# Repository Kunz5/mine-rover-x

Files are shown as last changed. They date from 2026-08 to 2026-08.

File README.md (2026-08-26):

# MineRoverX

**A four-wheeled ground robot that sweeps for buried metal, stops when it finds
something, and drops a marker where it stopped.**

Custom-designed chassis, 3D-printed rack-and-pinion sweep mechanism, ESP32
firmware, and a metal detector that had to be physically modified before it
could talk to a microcontroller at all.






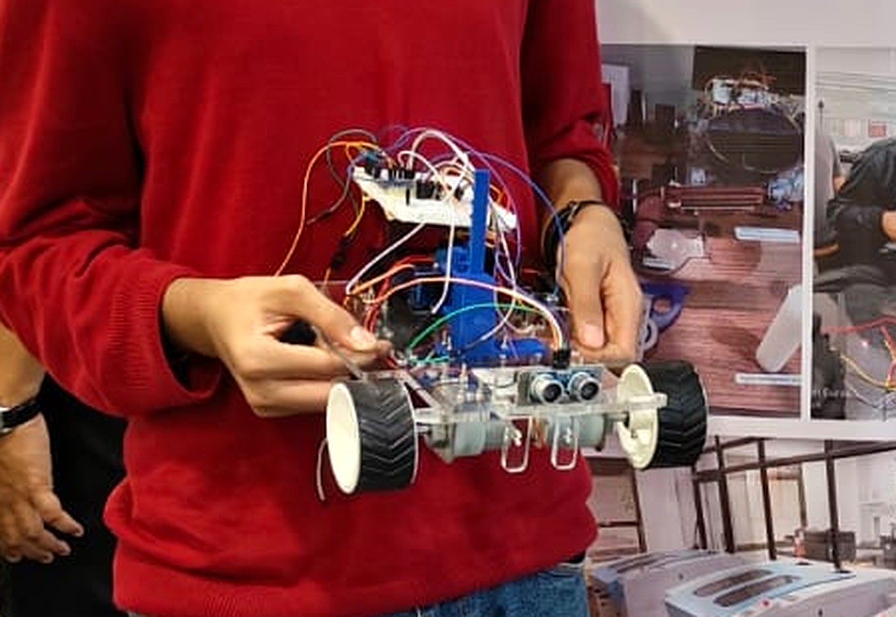
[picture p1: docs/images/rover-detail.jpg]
The rover


*The assembled rover, shown at the MAKERSPACE MS 101 exhibition. Visible: the
laser-cut acrylic chassis, 3D-printed wheel hubs, the blue printed rack and the
servo that drives it, the HC-SR04 ultrasonic module on the front edge, and the
ESP32 stack above.* **The metal detector head is not fitted in these
photographs** *— they were taken with the platform running its obstacle-avoidance
firmware.*

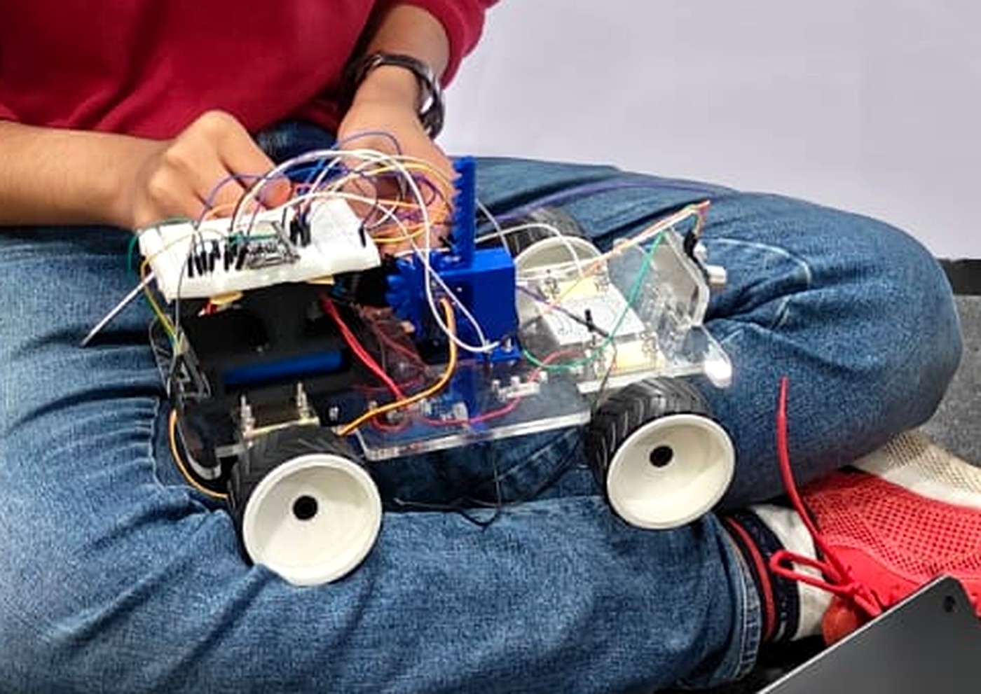
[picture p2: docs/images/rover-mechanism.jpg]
Rack and pinion detail


*The rack-and-pinion sweep mechanism, printed in blue: the toothed vertical rack
and the servo housing at its base. The CAD sources are in
[`hardware/cad/rack-and-pinion/`](hardware/cad/rack-and-pinion/).*

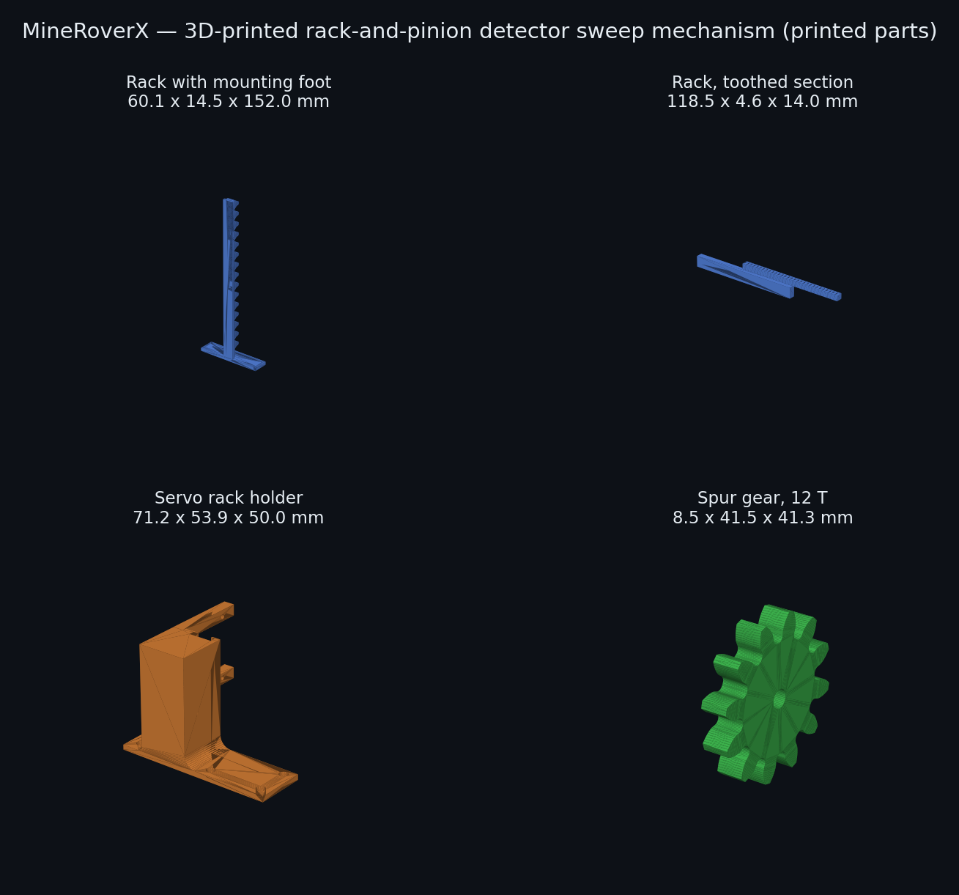
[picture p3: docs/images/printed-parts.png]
3D-printed parts


*The printed parts, rendered directly from the STL sources.*

---

## The problem

Landmine clearance is slow because it has to be. A deminer advances on foot,
sweeping a handheld detector in arcs, and every metallic return has to be
investigated by hand. The overwhelming majority of those returns are scrap —
nails, shell fragments, bottle caps — but each one is treated as live until
proven otherwise, because the cost of being wrong once is a person.

Two things about that process are mechanical rather than human: *moving the
detector head across the ground in a controlled pattern*, and *marking the exact
spot where a return occurred*. Those are the parts a machine can take over
without needing to make any judgement about what it found.

## What I built

MineRoverX is a small ground platform that does exactly those two jobs. It
drives, it carries a metal detector on a servo-driven sweep mechanism, it stops
when the detector alarms, and it drops a physical marker at that spot for a human
to investigate. It does not attempt to classify what it found, and it does not
attempt to decide whether anything is safe. That distinction is deliberate.

The engineering interest is not in the concept. It is in the three problems the
build actually threw at me.

---

## Problem 1 — the detector had no way to talk to anything

The metal detector module has no data pin. No serial, no comparator output, no
logic-level "found something" line. Its only output is an audible alarm.

So I opened it and **soldered directly onto the buzzer terminal**, and ran that
into a GPIO on the ESP32.

That solves the wiring and creates a signal-processing problem, because what
arrives at the pin is not a level — it is an **audio-frequency waveform**. While
the alarm is sounding, that line is flipping hundreds of times a second. A naive
`digitalRead(pin) == HIGH` would be wrong roughly half the times it sampled, and
would report detections and non-detections essentially at random.

The correct question is not *"is the line high"* but *"is the line oscillating"*.

So the firmware does envelope detection:

1. An interrupt on `CHANGE` counts every transition on the tapped line.
2. Every 100 ms, the accumulated edge count is read and cleared. Twenty or more
   edges in a window means a tone of at least ~100 Hz — the alarm is sounding.
3. A detection is only **committed** once the alarm has sounded continuously for
   two seconds. This rejects the short chirps the module emits at power-up and
   when it is swung quickly across uneven ground.
4. A brief dropout mid-alarm does not reset the accumulated hold. Only 400 ms of
   sustained silence releases it.

The `CAL` command prints the live edge rate against the threshold, so the
detector can be recalibrated in the field for different soil and different
battery voltages without recompiling.

```
# edges/100ms=63 threshold=20 toneHeld=1400/2000
```

This is the part of the project I would most want to be asked about. The
hardware limitation forced a genuinely different firmware design, and the
resulting detector is more robust than a clean digital output would have been —
because it measures *how long the alarm has been sounding*, not merely whether
it is on at the instant it was sampled.

---

## Problem 2 — v2 worked, and was still unsafe to drive

The firmware that actually ran on the rover (`firmware/v2_baseline/`, preserved
unmodified) demoed fine on a bench and contained three defects that only matter
on real ground:

| | Defect | Consequence |
|---|---|---|
| 1 | `pulseIn()` returns `0` on timeout; v2 tested `distance <= 15` | **A completely clear path read as an obstacle 0 cm away.** The rover braked on open ground. |
| 2 | The obstacle branch `return`ed before the serial read | **Once triggered, no command could be received** — including reverse. The rover had to be picked up. |
| 3 | Motion commands latched the motors on with no timeout | **A dropped serial link meant an uncommanded runaway** until it hit something or the battery died. |

For a platform whose purpose is to move slowly over ground that may contain
buried ordnance, defect 3 is the one that actually matters.

`firmware/v3/` is a rewrite, not a patch: a non-blocking state machine with no
`delay()` in `loop()`, serial serviced unconditionally on every iteration,
median-filtered ranging that fails toward "clear" instead of toward "obstacle",
a 1.2 s deadman timeout, hysteresis on the obstacle threshold, soft-start
ramping to protect the N20 gearboxes, real LEDC PWM at 20 kHz, and a latching
emergency stop.

**Full diagnosis: [`docs/firmware-postmortem.md`](docs/firmware-postmortem.md).**

### The v3 state machine

Commands set *intent*. State is derived from the sensors on every 20 ms control
tick — never assigned by the command handler. That separation is the fix for the
bug the test suite caught.

```mermaid
stateDiagram-v2
    [*] --> IDLE: boot, motors DISARMED
    IDLE --> DRIVING: F / B / L / R once ARMed
    DRIVING --> IDLE: S, or command timeout after 1.2 s
    DRIVING --> OBSTACLE_HOLD: range falls to 15 cm
    OBSTACLE_HOLD --> IDLE: range rises past 22 cm
    OBSTACLE_HOLD --> DRIVING: reverse or turn still permitted
    DRIVING --> TARGET_FOUND: alarm sustained 2 s
    IDLE --> TARGET_FOUND: alarm sustained 2 s
    TARGET_FOUND --> IDLE: CLEAR acknowledges
    IDLE --> ESTOP: ESTOP
    DRIVING --> ESTOP: ESTOP
    OBSTACLE_HOLD --> ESTOP: ESTOP
    ESTOP --> IDLE: CLEAR, then ARM
```

The 15 cm stop and 22 cm resume are deliberately different. A single threshold
made the rover chatter in and out of the hold at the boundary; the gap between
them is hysteresis.

---

## Problem 3 — testing embedded code without a board

Firmware that can only be tested by flashing it mostly doesn't get tested. Every
part of v3 that isn't a register write is pure logic, so I stubbed the Arduino
HAL and compile the sketch on a host machine.

```bash
cd test && g++ -std=c++17 -I. -o test_v3 test_v3.cpp && ./test_v3
```

```
42 passed, 0 failed
```

The suite covers ultrasonic out-of-range handling, median filtering, command
parsing and clamping, the deadman timeout, obstacle hysteresis, the full
envelope-detection state machine, the marker drop sequence, soft-start ramping,
and emergency stop latching. Simulated hardware — echo timings, buzzer edge
counts, elapsed time — is injected by the tests.

**It immediately earned its keep.** The first version of v3 assigned the state
machine directly from the command handler, so reversing away from an obstacle
overwrote `OBSTACLE_HOLD` and a forward command became legal again *while the
obstacle was still 10 cm ahead*. The tests caught it in under a second. v3 now
separates operator *intent* from machine *state*, and derives state from the
live sensor reading on every control tick.

---

## Mechanical design

The chassis and the detector sweep mechanism are my own, modelled in Fusion 360
and 3D printed. Every off-the-shelf component — the ESP32 board, L298N, N20
motors, SG90, relay, 18650 holder — was modelled or sourced into the assembly
first, so parts were fit-checked digitally before anything was printed.

| Part | Size | Role |
|---|---|---|
| Rack with mounting foot | 60.1 x 14.5 x 152.0 mm | 152 mm of linear travel for the detector head |
| Rack, toothed section | 118.5 x 4.6 x 14.0 mm | Drive tooth profile |
| Servo rack holder | 71.2 x 53.9 x 50.0 mm | Mounts the SG90 and constrains the rack |
| Spur gear, 12 T | 41.5 mm dia. x 8.5 mm | Servo output to rack |

Both the chassis and the sweep mechanism were iterated — chassis v1 → v2, dumper
mechanism v4 → v5. Sources are in [`hardware/cad/`](hardware/cad/) as STEP,
STL, 3MF and F3D.

---

## Hardware

ESP32 DOIT DevKit V1 · L298N dual H-bridge · 4x N20 gear motors · HC-SR04
ultrasonic · IR obstacle module · metal detector module (buzzer line tapped) ·
SG90 servo · 1-channel relay · 18650 pack

```mermaid
flowchart LR
    subgraph POWER["Power"]
        BAT["18650 pack"]
    end

    subgraph SENSE["Sensing"]
        MD["Metal detector<br/>buzzer terminal tapped"]
        US["HC-SR04<br/>ultrasonic"]
        IR["IR obstacle<br/>module"]
    end

    subgraph BRAIN["Controller"]
        ESP["ESP32 DOIT DevKit V1<br/>240 MHz"]
    end

    subgraph ACT["Actuation"]
        L298["L298N<br/>dual H-bridge"]
        MOT["4x N20 gear motors<br/>tank steering"]
        SRV["SG90 servo<br/>rack and pinion"]
        MK["Marker drop"]
    end

    HOST["Host laptop<br/>USB serial 115200"]

    BAT --> L298
    BAT --> ESP
    MD -->|"GPIO 34 · audio waveform<br/>interrupt on CHANGE"| ESP
    US -->|"TRIG 17 / ECHO 16"| ESP
    IR -->|"GPIO 4 · active LOW"| ESP
    ESP -->|"ENA 27 · IN1 26 · IN2 25<br/>ENB 5 · IN3 18 · IN4 19"| L298
    L298 --> MOT
    ESP -->|"GPIO 13 · 50 Hz PWM"| SRV
    SRV --> MK
    ESP <-->|"commands / 4 Hz CSV telemetry"| HOST
```

> **Power note.** The ESP32 must not be run from the L298N's 5 V regulator while
> the motors are loaded — the rail sags on current spikes and the ESP32 browns
> out mid-command. Separate the supplies and tie the grounds.

Full pin map and power warnings: [`hardware/BOM.md`](hardware/BOM.md).

---

## Command protocol

Serial, 115200 baud, newline-terminated. Boots **disarmed**.

| Command | Effect |
|---|---|
| `ARM` / `DISARM` | Enable or disable motion |
| `F` `B` `L` `R` `S` | Forward, reverse, left, right, stop |
| `SPD <0-255>` | Target speed; ramped, not applied instantly |
| `MARK` | Drop a marker |
| `CAL` | Print live detector edge rate vs. threshold |
| `ESTOP` / `CLEAR` | Latch / release emergency stop |
| `?` | Status |

Telemetry streams at 4 Hz as CSV, so a host can log and plot a sweep:

```
T,<ms>,<state>,<range_cm>,<speed>,<detect>,<edges>,<ir>
```

---

## Status — what is and isn't true

- The rover is **built and has driven** under `firmware/v2_baseline/`.
- The detector buzzer tap is **physically done and works** — though it is not
  fitted in the photographs above, which show the platform running its
  obstacle-avoidance firmware at an exhibition.
- `firmware/v3/` is **fully tested on host but has not yet been flashed to the
  rover.** Everything above about v3 describes verified logic, not verified
  field behaviour.
- The metal detector and servo GPIO assignments in v3 (34 and 13) are
  **proposed**, not yet confirmed against the physical wiring. Every other pin
  is read directly from the firmware that ran.
- There is **no autonomous navigation.** The rover is driven over serial; it
  stops and marks on its own, but it does not plan its own path. Coverage
  planning is a separate problem I have worked on
  [here](https://github.com/Kunz5/sweep-planner).

## Limitations

- Tank steering with no encoders, so there is no odometry and no position
  estimate. A marker records *that* something was found, not *where* in any
  coordinate frame.
- The detector reports presence only. It cannot discriminate ordnance from
  scrap, which is the actual hard problem in demining.
- Ultrasonic obstacle detection only — nothing detects a drop-off or a hole.
- No IP rating, no weather sealing, indoor and dry ground only.
- Wi-Fi and Bluetooth on the ESP32 are unused; control is wired serial.

## Next

Wheel encoders for closed-loop odometry, so detections can be logged against a
position. Automatic lawnmower sweep using the coverage planner. Logging
detections to SD with timestamps and edge-rate traces.

---

## Repository layout

```
firmware/v2_baseline/   the firmware that actually drove the rover, unmodified
firmware/v3/            rewrite: non-blocking, deadman, envelope detection
test/                   host-side test suite (42 tests) + Arduino HAL stub
hardware/BOM.md         parts, pin map, power notes
hardware/cad/           chassis, rack-and-pinion, dumper mechanism sources
docs/firmware-postmortem.md   what was wrong with v2 and why it mattered
```

---

## Timeline

The rover was designed and built in **June 2025** — the chassis and sweep
mechanism in Fusion 360, the v2 firmware that drove it, and the buzzer-line tap
on the detector.

Firmware v3, the host test harness, and this documentation were written in
**August 2026**, when the project was cleaned up and published. The v2 source in
`firmware/v2_baseline/` is unmodified from the original build.

---

*Kunaal Nirmal Khanwani · built June 2025 at the IIT Bombay Makerspace workshop, published August 2026 · MIT licensed.*

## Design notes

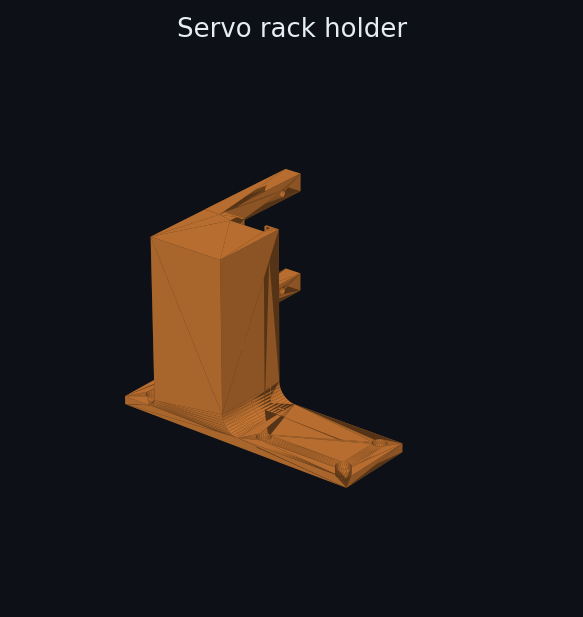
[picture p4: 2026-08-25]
docs/images/servo_rack_holder.png

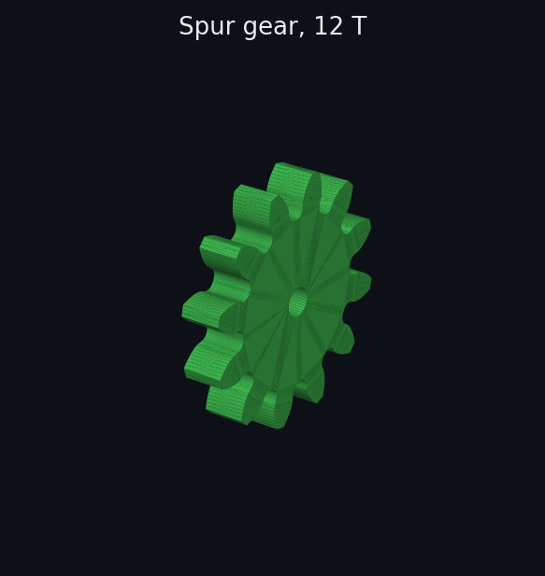
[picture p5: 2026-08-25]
docs/images/spur_gear_12t.png

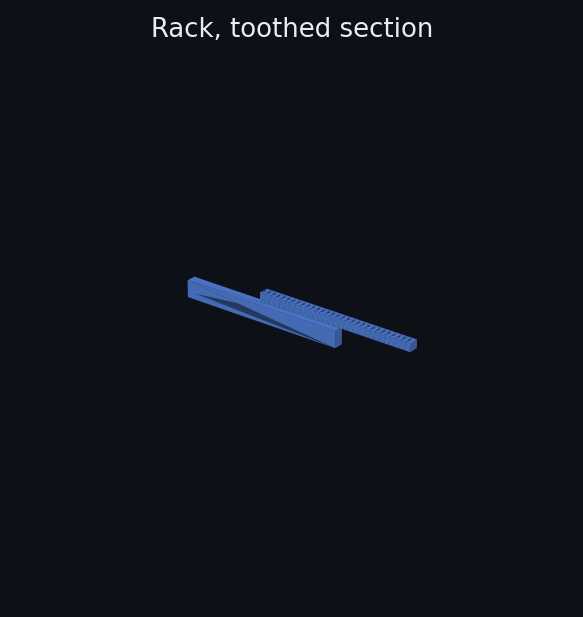
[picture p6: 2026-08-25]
docs/images/rack_gear.png

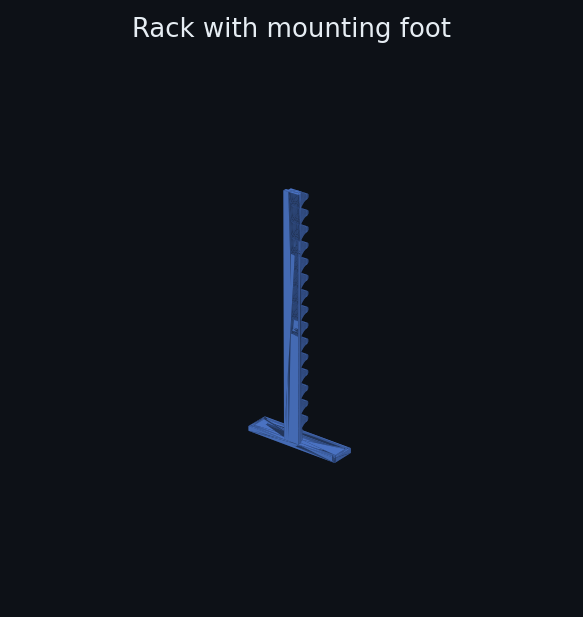
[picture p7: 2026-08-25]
docs/images/rack_full.png

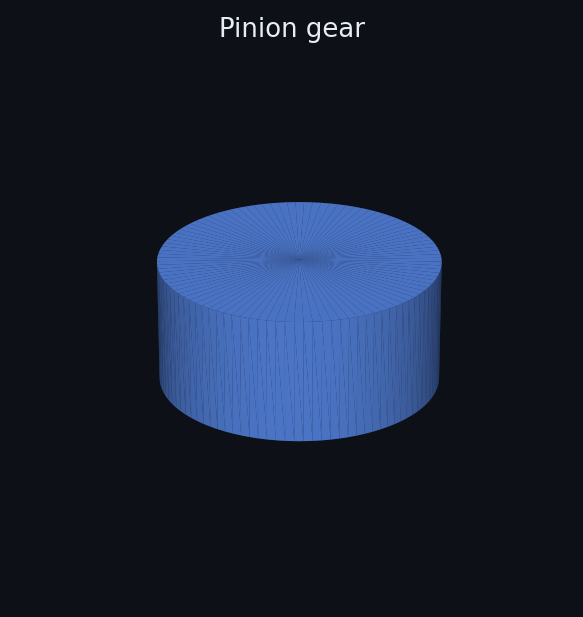
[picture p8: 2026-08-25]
docs/images/pinion_gear.png

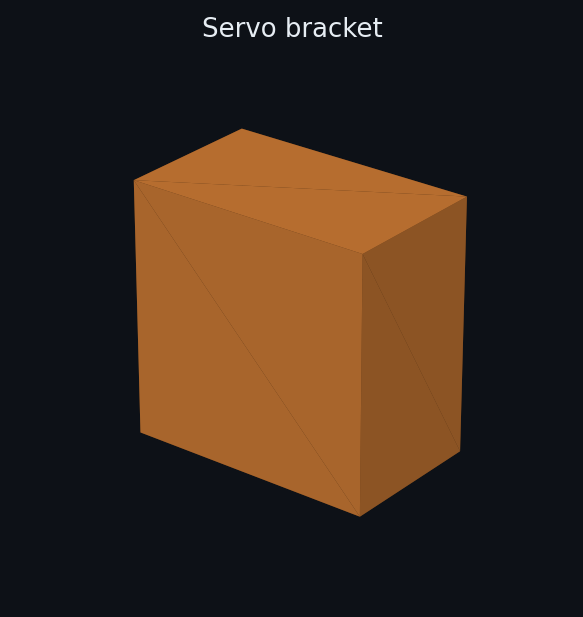
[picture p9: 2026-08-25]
docs/images/servo_bracket.png

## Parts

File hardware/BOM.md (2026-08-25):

# Bill of materials

## Electronics

| Part | Role | Notes |
|---|---|---|
| ESP32 DOIT DevKit V1 (38-pin) | Controller | 240 MHz dual-core, Wi-Fi/BT unused so far |
| L298N dual H-bridge | Motor driver | Drives left and right sides as two channels |
| N20 DC gear motors x4 | Drive | Wired as two pairs, tank steering |
| HC-SR04 | Ultrasonic rangefinder | Forward obstacle detection, 2–400 cm |
| IR obstacle module | Secondary proximity | Digital, active LOW |
| Metal detector sensor module | **Primary payload** | Digital comparator output |
| SG90 micro servo | Marker-drop / head actuation | Driven through the printed rack and pinion |
| 1-channel relay module | Switched auxiliary load | |
| 18650 cells + holder | Power | |

## Pin map

Pins marked **verified** are read directly from the firmware that ran on the
physical rover. Pins marked *proposed* are assignments chosen for v3 and are
not yet confirmed against the wiring.

| Signal | GPIO | Status |
|---|---|---|
| L298N ENA (right PWM) | 27 | verified |
| L298N IN1 / IN2 | 26 / 25 | verified |
| L298N ENB (left PWM) | 5 | verified |
| L298N IN3 / IN4 | 18 / 19 | verified |
| HC-SR04 TRIG / ECHO | 17 / 16 | verified |
| IR obstacle module | 4 | verified |
| Metal detector output | 34 | *proposed* — input-only pin, ADC-capable |
| Marker servo | 13 | *proposed* |

## Power notes

The L298N drops roughly 1.4–2 V across its output stage, so motor voltage sits
meaningfully below pack voltage. The ESP32 must not be powered from the L298N's
5 V regulator while the motors are under load — the rail sags on current spikes
and the ESP32 browns out mid-command. Separate the logic and motor supplies and
tie the grounds.

GPIO 34 is input-only and has no internal pull-up, so the detector module must
drive it actively or an external pull-down is required.

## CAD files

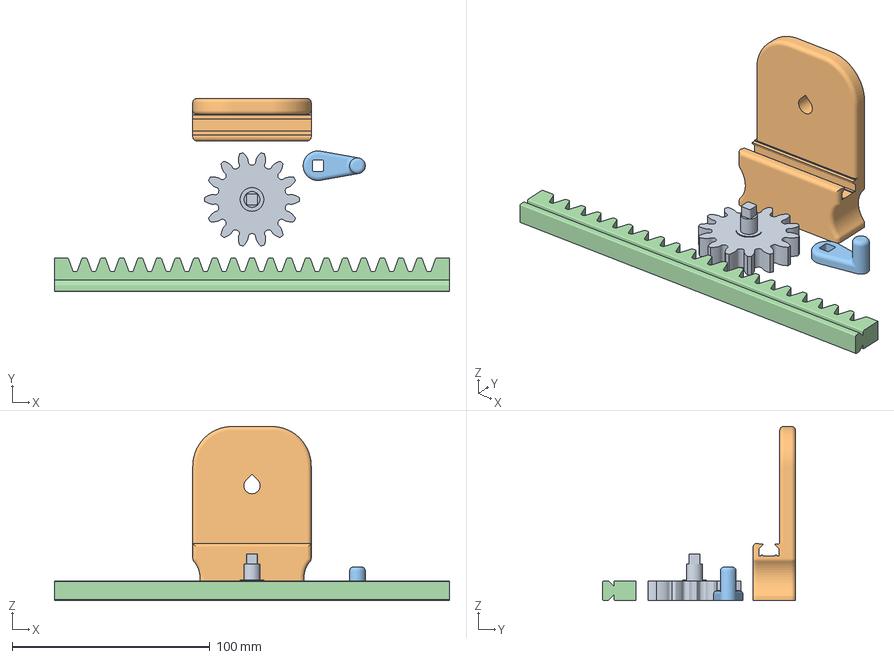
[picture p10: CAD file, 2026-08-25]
hardware/cad/rack-and-pinion/rack_and_pinion_assembly.3mf
200.0 x 97.7 x 88.1 mm
Pinion.stl
Body.stl
Crank.stl
Rack.stl

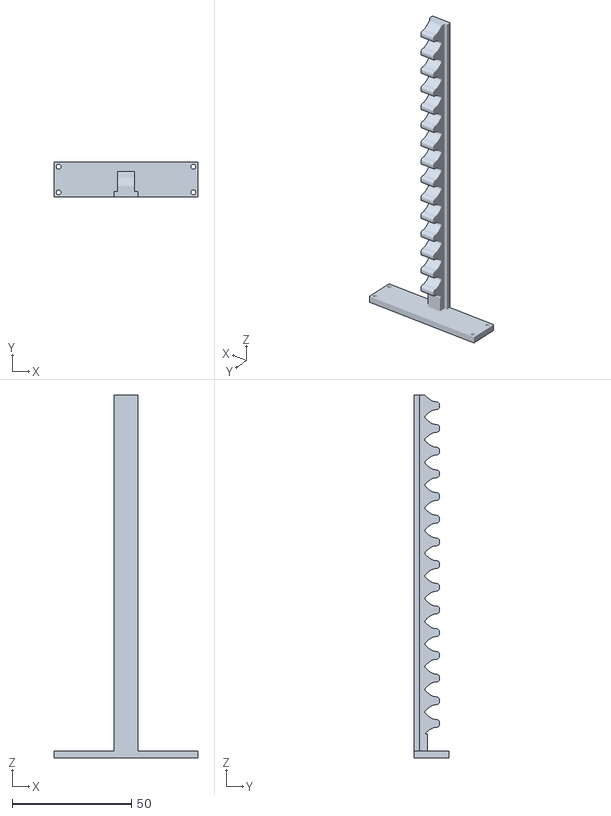
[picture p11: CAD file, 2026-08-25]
hardware/cad/rack-and-pinion/rack_full.stl
60.1 x 14.5 x 152.0

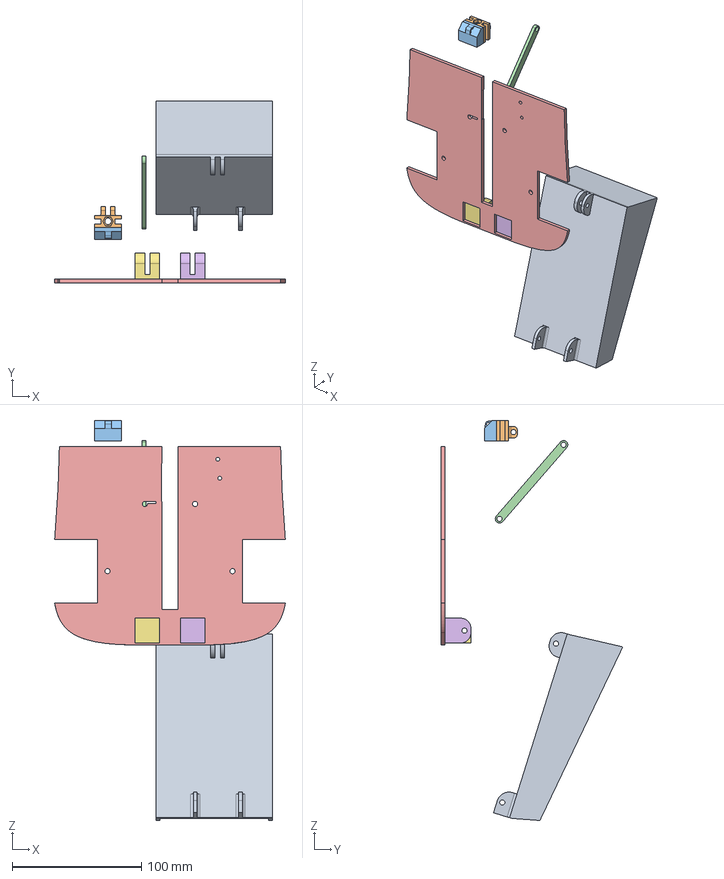
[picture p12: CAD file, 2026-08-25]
hardware/cad/dumper-mechanism/dumper_v5.step
178.4 x 140.3 x 308.9 mm
damper umper_trolley v1
_slider v1
connecting rod v1
bed v1

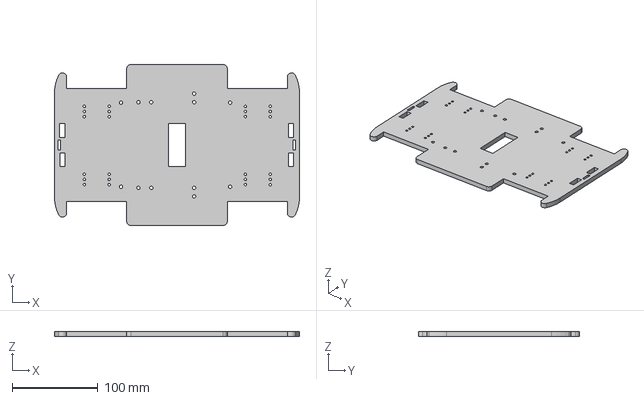
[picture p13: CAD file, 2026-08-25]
hardware/cad/chassis/chassis_v2.step
286.0 x 188.1 x 6.00 mm

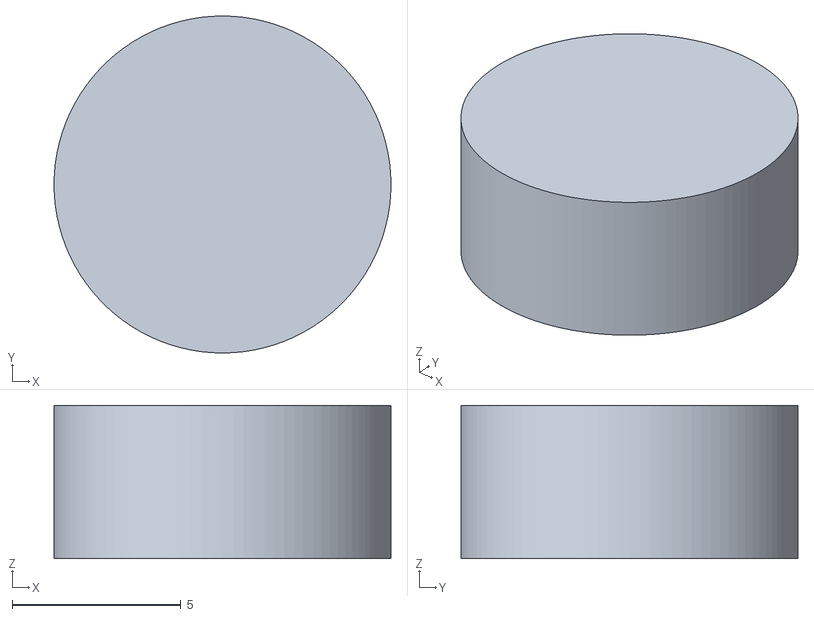
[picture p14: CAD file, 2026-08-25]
hardware/cad/rack-and-pinion/pinion_gear.stl
10.0 x 10.0 x 4.55

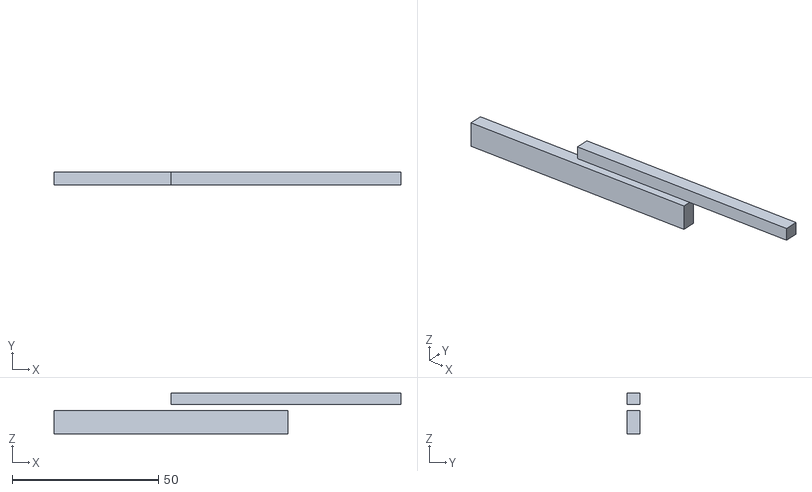
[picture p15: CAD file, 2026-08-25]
hardware/cad/rack-and-pinion/rack_gear.stl
118.5 x 4.55 x 14.0

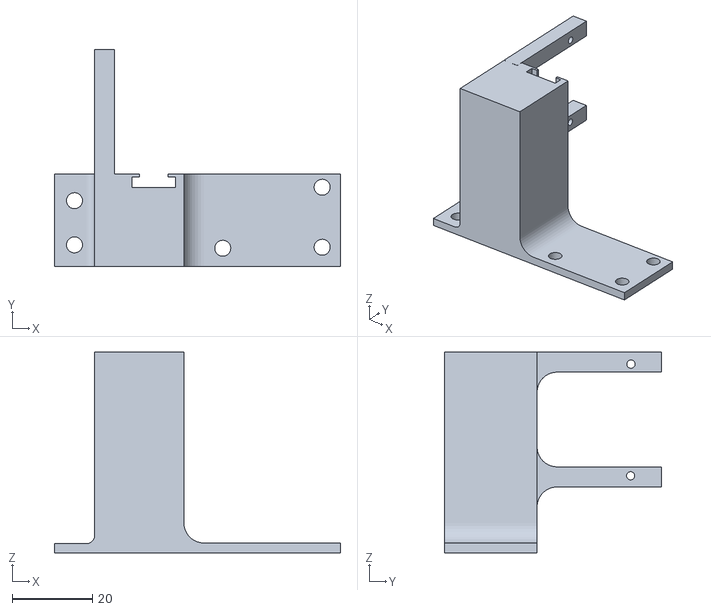
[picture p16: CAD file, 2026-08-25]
hardware/cad/rack-and-pinion/servo_rack_holder.stl
71.2 x 53.9 x 50.0

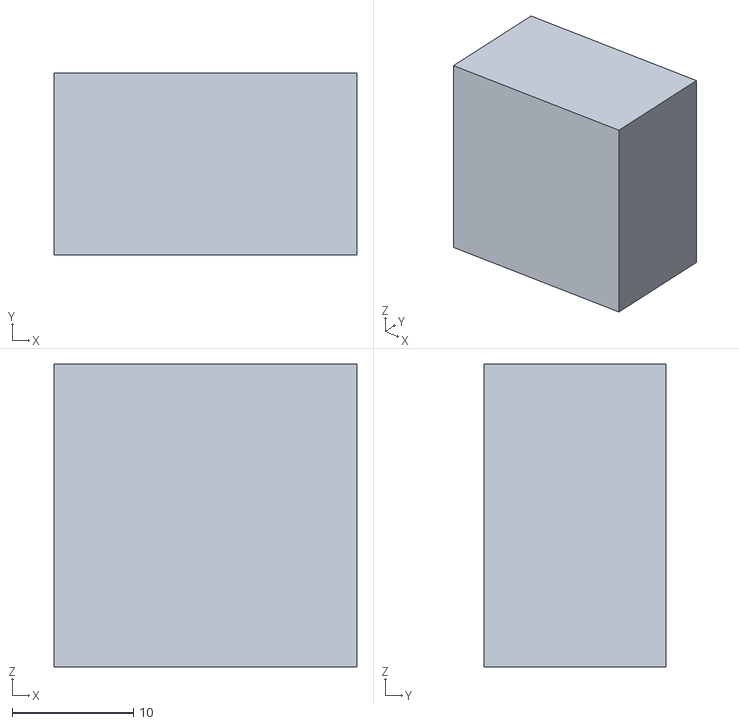
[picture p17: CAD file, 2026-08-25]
hardware/cad/rack-and-pinion/servo_bracket.stl
25.0 x 15.0 x 25.0

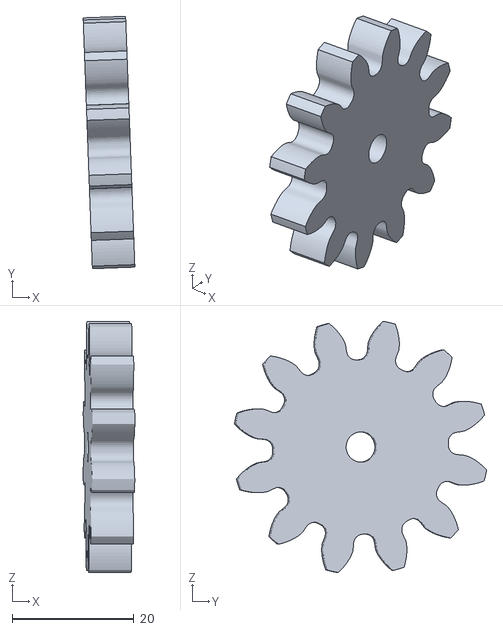
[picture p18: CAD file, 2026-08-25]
hardware/cad/rack-and-pinion/spur_gear_12t.stl
8.51 x 41.5 x 41.3

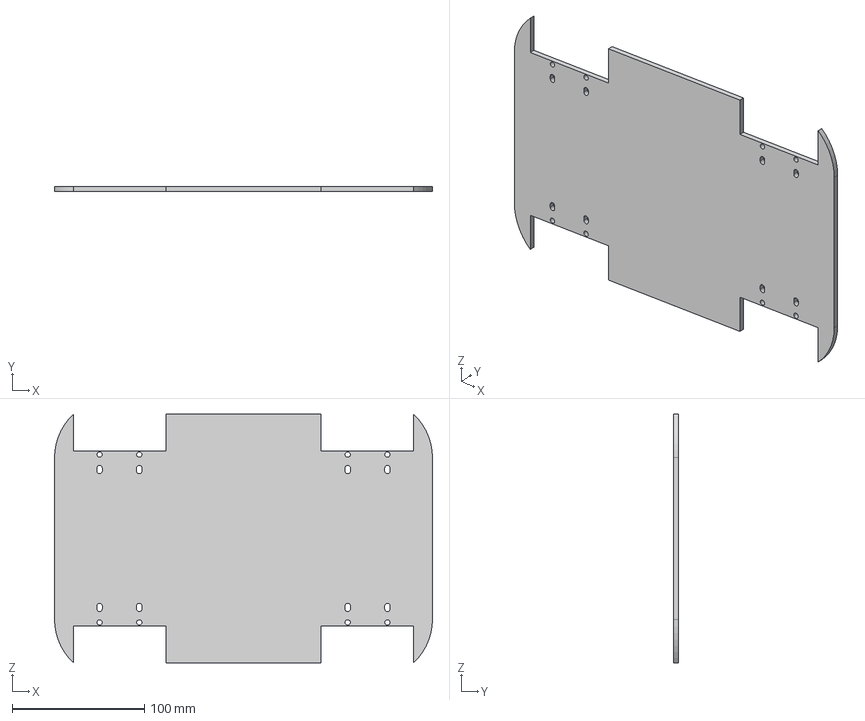
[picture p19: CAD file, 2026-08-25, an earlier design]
hardware/cad/chassis/chassis_v1.step
286.0 x 4.00 x 188.1 mm

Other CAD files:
hardware/cad/dumper-mechanism/dumper_v4.f3d

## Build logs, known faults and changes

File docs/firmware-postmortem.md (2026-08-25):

# Firmware post-mortem: what was wrong with v2

v2 is the firmware that actually drove the rover. It worked well enough to demo,
which is exactly why the defects in it are worth writing down — none of them
show up on a bench, and all three of them matter the moment the rover is on
ground you care about.

The v2 source is preserved unmodified at [`firmware/v2_baseline/`](../firmware/v2_baseline/)
so the diagnosis can be checked against the real thing.

---

## Defect 1 — the failure mode was inverted

```c
long duration = pulseIn(echoPin, HIGH, 20000);
float distance = duration * 0.0343 / 2;   // → 0.0 when duration == 0
...
if (distance <= stopDistance) {           // 0 <= 15  is TRUE
  stopMotors();
```

`pulseIn()` returns `0` when it times out — that is, when **nothing echoes
back**, which happens when the path ahead is clear beyond the sensor's range.
v2 converts that to `0.0 cm` and compares it against the 15 cm stop threshold.

So an entirely clear path was read as *an obstacle zero centimetres away*, and
the rover braked. The one condition the sensor is meant to give you confidence
about is the one that stopped it.

**Fix (v3):** `pingOnce()` returns `MAX_RANGE_CM` on timeout, and also rejects
returns below the HC-SR04's 2 cm spec floor. "No echo" now means "nothing
there", which is both correct and the safe direction to fail in.

---

## Defect 2 — the rover could brick itself

```c
if (distance <= stopDistance) {
  stopMotors();
  Serial.println("Object detected within 15 cm! Stopping...");
  delay(100);
  return;                    // ← skips the serial read below
}
...
if (Serial.available() > 0) { /* read command */ }
```

The early `return` skips command handling entirely. Once an obstacle was inside
15 cm — or once defect 1 fired, which was most of the time — **no command could
be received at all**, including reverse. The rover could not be driven out of
the situation it had driven into. It had to be picked up.

**Fix (v3):** `serviceSerial()` is called unconditionally at the top of every
`loop()` iteration, before any state logic. There is no control path that can
skip it. Forward motion is refused while an obstacle is close; reverse and
turns stay available.

---

## Defect 3 — no deadman switch

```c
void moveForward() {
  digitalWrite(in1, HIGH); ...
  analogWrite(enA, motorSpeed);
}                              // returns; motors stay on indefinitely
```

Motion commands latch the motors on and return. Nothing turns them off except
another command. If the USB cable is pulled, the host crashes, or the serial
link glitches, the rover keeps driving until it hits something or the battery
dies.

For a platform whose entire purpose is to move slowly over ground that may
contain buried ordnance, an uncommanded runaway is the worst available
behaviour.

**Fix (v3):** every accepted command stamps `lastCommandMs`. The control tick
stops the motors if no command has arrived within `CMD_TIMEOUT_MS` (1.2 s).
Continuous motion requires a host that is still alive and still talking.

---

## Also fixed

| Issue in v2 | v3 |
|---|---|
| `analogWrite()` on ESP32 — a no-op on arduino-esp32 2.x, a shim on 3.x | LEDC PWM at 20 kHz, with a compile-time branch covering both core versions |
| Serial flooded at several kHz — `println` on every loop iteration | Fixed-rate CSV telemetry at 4 Hz, parseable by a host logger |
| Single unfiltered ultrasonic reading | Median-of-3, which rejects one spurious return per sample |
| Instant full PWM from standstill | Soft-start ramp (12 counts per 20 ms tick) — full torque from rest is what strips N20 gearboxes |
| Hard threshold at 15 cm, so the rover chattered at the boundary | Hysteresis: stop at 15 cm, resume only above 22 cm |
| No emergency stop | `ESTOP` latches; requires `CLEAR` then `ARM` to recover |
| Motors live at boot | Boots disarmed; `ARM` required before any motion |
| `v2.ino` and `ultransonic.ino` were byte-identical duplicates | Single source of truth |

---

## A bug the tests caught in v3 itself

The first version of v3 assigned the state machine directly from the command
handler:

```c
motion = m;
state  = (m == Motion::STOP) ? State::IDLE : State::DRIVING;   // wrong
```

The host test suite caught the consequence immediately: reversing away from an
obstacle overwrote `OBSTACLE_HOLD` with `DRIVING`, after which a forward command
was accepted again — while the obstacle was still 10 cm ahead. A latched state
flag had been allowed to disagree with the sensor.

v3 now separates the two. Commands set *intent* (`motion`); `updateState()`
derives *state* from the live range reading on every control tick. State is a
function of the world, not of the last thing the operator typed.

This is the argument for [`test/`](../test/) in a sentence: the bug was found in
a fraction of a second on a laptop, rather than by watching a rover drive into
something.

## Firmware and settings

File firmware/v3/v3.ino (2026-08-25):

/**
 * MineRoverX — Firmware v3
 * ESP32 + L298N + HC-SR04 + metal-detector module + marker servo
 *
 * v3 is a rewrite of v2, not a patch. v2 worked on the bench but had three
 * defects that made it unsafe to drive over live ground. See
 * docs/firmware-postmortem.md for the full diagnosis. In short:
 *
 *   1. pulseIn() returns 0 on timeout, and v2 tested `distance <= STOP_CM`,
 *      so *no echo at all* was read as *obstacle at 0 cm*. Clear ground
 *      triggered an emergency stop.
 *   2. The obstacle branch ran stop(); delay(100); return; which skipped the
 *      serial read, so once triggered the rover could not receive any command,
 *      including reverse. It had to be physically moved.
 *   3. Motion commands latched the motors on with no timeout. A dropped serial
 *      link meant the rover drove until it hit something or the battery died.
 *
 * v3 is a non-blocking state machine. There is no delay() in loop(). Serial is
 * always serviced. Motion requires a live command or it stops on its own.
 */

#include <ESP32Servo.h>

// ─────────────────────────────────────────────────────────────────────────────
// Pin map — these match the physical build
// ─────────────────────────────────────────────────────────────────────────────
static const uint8_t PIN_ENA  = 27;   // L298N ENA — right side PWM
static const uint8_t PIN_IN1  = 26;
static const uint8_t PIN_IN2  = 25;
static const uint8_t PIN_ENB  = 5;    // L298N ENB — left side PWM
static const uint8_t PIN_IN3  = 18;
static const uint8_t PIN_IN4  = 19;

static const uint8_t PIN_TRIG = 17;   // HC-SR04
static const uint8_t PIN_ECHO = 16;

static const uint8_t PIN_IR     = 4;  // IR obstacle module (active LOW)
static const uint8_t PIN_DETECT = 34; // metal detector BUZZER line, tapped (input-only pin)
static const uint8_t PIN_SERVO  = 13; // marker-drop / head-lift servo

// ─────────────────────────────────────────────────────────────────────────────
// Tunables
// ─────────────────────────────────────────────────────────────────────────────
static const uint16_t PWM_FREQ_HZ   = 20000;  // 20 kHz — above audible range,
                                              // stops the gearmotors whining
static const uint8_t  PWM_BITS      = 8;      // 0..255, keeps v2's speed scale

static const float    MAX_RANGE_CM  = 400.0f; // HC-SR04 spec ceiling
static const uint32_t ECHO_TIMEOUT_US = 25000; // ~4.3 m round trip
static const float    STOP_CM       = 15.0f;  // obstacle hold threshold
static const float    CLEAR_CM      = 22.0f;  // must exceed this to resume
                                              // (hysteresis: stops the rover
                                              //  oscillating at the boundary)

static const uint32_t CMD_TIMEOUT_MS  = 1200; // deadman — no command, no motion
static const uint32_t RANGE_PERIOD_MS = 50;   // 20 Hz ranging
static const uint32_t CTRL_PERIOD_MS  = 20;   // 50 Hz control tick
static const uint32_t TELEM_PERIOD_MS = 250;  // 4 Hz telemetry

static const uint8_t  RAMP_STEP     = 12;     // PWM counts per control tick.
                                              // Soft-start: full torque from
                                              // standstill strips N20 gears.
static const uint8_t  DEFAULT_SPEED = 180;

// ── Metal detector: envelope detection on a tapped buzzer line ─────────────
// The detector module has no data output of any kind. Its only indication that
// it has found something is an audible alarm, so its buzzer terminal is
// soldered directly to a GPIO. That line carries an audio-frequency waveform
// while the alarm sounds, and sits idle otherwise.
//
// This means a level test is the wrong instrument. digitalRead() on an active
// buzzer line returns a value that flips hundreds of times a second, so
// `digitalRead(pin) == HIGH` would be wrong roughly half the times it sampled.
// The question is not "is the line high" but "is the line oscillating".
//
// So: count edges with an interrupt, integrate them over a fixed window, and
// treat a sufficiently high edge rate as "alarm sounding". A detection is only
// committed once the alarm has sounded continuously for DETECT_CONFIRM_MS,
// which rejects the short chirps the module emits on power-up and when it is
// swung quickly over uneven ground.
static const uint32_t DETECT_WINDOW_MS  = 100;   // envelope integration window
static const uint16_t DETECT_MIN_EDGES  = 20;    // >= 20 edges/100ms => >= 100 Hz
static const uint32_t DETECT_CONFIRM_MS = 2000;  // sustained alarm before commit
static const uint32_t DETECT_RELEASE_MS = 400;   // silence before the hold resets

static const int SERVO_STOWED = 20;           // marker arm retracted
static const int SERVO_DROP   = 110;          // marker released
static const uint32_t DROP_HOLD_MS = 400;

// ─────────────────────────────────────────────────────────────────────────────
// PWM compatibility. arduino-esp32 3.x replaced the ledcSetup/ledcAttachPin
// pair with a single ledcAttach(pin, freq, bits). v2 used analogWrite(), which
// only exists as a shim on 3.x — on 2.x it silently does nothing on these pins.
// ─────────────────────────────────────────────────────────────────────────────
#if ESP_ARDUINO_VERSION_MAJOR >= 3
  static inline void pwmInit(uint8_t pin, uint8_t) { ledcAttach(pin, PWM_FREQ_HZ, PWM_BITS); }
  static inline void pwmWrite(uint8_t pin, uint8_t, uint8_t duty) { ledcWrite(pin, duty); }
#else
  static inline void pwmInit(uint8_t pin, uint8_t ch) {
    ledcSetup(ch, PWM_FREQ_HZ, PWM_BITS);
    ledcAttachPin(pin, ch);
  }
  static inline void pwmWrite(uint8_t, uint8_t ch, uint8_t duty) { ledcWrite(ch, duty); }
#endif
static const uint8_t CH_A = 0, CH_B = 1;

// ─────────────────────────────────────────────────────────────────────────────
// State
// ─────────────────────────────────────────────────────────────────────────────
enum class Motion : uint8_t { STOP, FWD, REV, LEFT, RIGHT };
enum class State  : uint8_t { IDLE, DRIVING, OBSTACLE_HOLD, TARGET_FOUND, ESTOP };

static State   state        = State::IDLE;
static Motion  motion       = Motion::STOP;
static bool    motorsArmed  = false;
static uint8_t targetSpeed  = DEFAULT_SPEED;
static uint8_t currentSpeed = 0;          // ramped toward targetSpeed
static float   rangeCm      = MAX_RANGE_CM;
static bool    detectLatched = false;

static volatile uint32_t edgeCount = 0;   // written from ISR
static uint16_t lastEdgeRate  = 0;        // edges in the most recent window
static uint32_t toneHeldMs    = 0;        // how long the alarm has sounded
static uint32_t silenceMs     = 0;
static bool     toneConfirmed = false;
static uint32_t lastDetectMs  = 0;

static uint32_t lastCommandMs = 0;
static uint32_t lastRangeMs   = 0;
static uint32_t lastCtrlMs    = 0;
static uint32_t lastTelemMs   = 0;

static Servo markerServo;
static String rxBuffer;

// ─────────────────────────────────────────────────────────────────────────────
// Ranging
// ─────────────────────────────────────────────────────────────────────────────

/** One HC-SR04 ping. Returns MAX_RANGE_CM when nothing echoes back.
 *  This is the fix for defect 1: "no echo" means "nothing is there",
 *  which is the *safest* reading, not the most dangerous one. */
static float pingOnce() {
  digitalWrite(PIN_TRIG, LOW);
  delayMicroseconds(2);
  digitalWrite(PIN_TRIG, HIGH);
  delayMicroseconds(10);
  digitalWrite(PIN_TRIG, LOW);

  uint32_t us = pulseIn(PIN_ECHO, HIGH, ECHO_TIMEOUT_US);
  if (us == 0) return MAX_RANGE_CM;             // timeout → out of range
  float cm = (us * 0.0343f) * 0.5f;
  if (cm < 2.0f || cm > MAX_RANGE_CM) return MAX_RANGE_CM;  // below spec floor
  return cm;
}

/** Median of three pings. Ultrasonic returns are noisy over grass and gravel —
 *  a single spurious short reading would otherwise brake the rover mid-sweep.
 *  Median rejects one outlier at a cost of ~2 extra pings. */
static float pingMedian3() {
  float a = pingOnce(), b = pingOnce(), c = pingOnce();
  if (a > b) { float t = a; a = b; b = t; }
  if (b > c) { float t = b; b = c; c = t; }
  if (a > b) { float t = a; a = b; b = t; }
  return b;
}

/** ISR: one increment per transition on the tapped buzzer line. */
static void IRAM_ATTR onDetectorEdge() { edgeCount++; }

/** Integrate edges over DETECT_WINDOW_MS and decide whether the alarm is
 *  sounding. Returns true on the window in which a detection is first
 *  confirmed. */
static bool serviceDetector(uint32_t now) {
  if (now - lastDetectMs < DETECT_WINDOW_MS) return false;
  lastDetectMs = now;

  noInterrupts();
  uint32_t edges = edgeCount;
  edgeCount = 0;
  interrupts();
  lastEdgeRate = (edges > 65535) ? 65535 : (uint16_t)edges;

  bool wasConfirmed = toneConfirmed;
  if (lastEdgeRate >= DETECT_MIN_EDGES) {
    toneHeldMs += DETECT_WINDOW_MS;
    silenceMs = 0;
  } else {
    silenceMs += DETECT_WINDOW_MS;
    // A brief dropout mid-alarm should not reset the accumulated hold; only
    // sustained silence does.
    if (silenceMs >= DETECT_RELEASE_MS) { toneHeldMs = 0; toneConfirmed = false; }
  }
  toneConfirmed = (toneHeldMs >= DETECT_CONFIRM_MS);
  return toneConfirmed && !wasConfirmed;
}

// ─────────────────────────────────────────────────────────────────────────────
// Motor primitives
// ─────────────────────────────────────────────────────────────────────────────
static void applyMotion(Motion m, uint8_t duty) {
  switch (m) {
    case Motion::FWD:
      digitalWrite(PIN_IN1, HIGH); digitalWrite(PIN_IN2, LOW);
      digitalWrite(PIN_IN3, HIGH); digitalWrite(PIN_IN4, LOW); break;
    case Motion::REV:
      digitalWrite(PIN_IN1, LOW);  digitalWrite(PIN_IN2, HIGH);
      digitalWrite(PIN_IN3, LOW);  digitalWrite(PIN_IN4, HIGH); break;
    case Motion::LEFT:
      digitalWrite(PIN_IN1, HIGH); digitalWrite(PIN_IN2, LOW);
      digitalWrite(PIN_IN3, LOW);  digitalWrite(PIN_IN4, HIGH); break;
    case Motion::RIGHT:
      digitalWrite(PIN_IN1, LOW);  digitalWrite(PIN_IN2, HIGH);
      digitalWrite(PIN_IN3, HIGH); digitalWrite(PIN_IN4, LOW);  break;
    case Motion::STOP:
    default:
      digitalWrite(PIN_IN1, LOW); digitalWrite(PIN_IN2, LOW);
      digitalWrite(PIN_IN3, LOW); digitalWrite(PIN_IN4, LOW);
      duty = 0; break;
  }
  pwmWrite(PIN_ENA, CH_A, duty);
  pwmWrite(PIN_ENB, CH_B, duty);
}

static void halt(const char* why) {
  motion = Motion::STOP;
  currentSpeed = 0;
  applyMotion(Motion::STOP, 0);
  if (why) { Serial.print(F("# halt: ")); Serial.println(why); }
}

// ─────────────────────────────────────────────────────────────────────────────
// Marker drop — non-blocking, driven from the control tick
// ─────────────────────────────────────────────────────────────────────────────
static bool     dropActive = false;
static uint32_t dropStartMs = 0;

static void beginMarkerDrop() {
  markerServo.write(SERVO_DROP);
  dropActive  = true;
  dropStartMs = millis();
  Serial.println(F("# marker: released"));
}

static void serviceMarker(uint32_t now) {
  if (dropActive && now - dropStartMs >= DROP_HOLD_MS) {
    markerServo.write(SERVO_STOWED);
    dropActive = false;
  }
}

// ─────────────────────────────────────────────────────────────────────────────
// Command handling — this ALWAYS runs, in every state. Defect 2 was caused by
// a control path that could skip it.
// ─────────────────────────────────────────────────────────────────────────────
static void printStatus() {
  Serial.print(F("# state="));
  switch (state) {
    case State::IDLE:          Serial.print(F("IDLE")); break;
    case State::DRIVING:       Serial.print(F("DRIVING")); break;
    case State::OBSTACLE_HOLD: Serial.print(F("OBSTACLE_HOLD")); break;
    case State::TARGET_FOUND:  Serial.print(F("TARGET_FOUND")); break;
    case State::ESTOP:         Serial.print(F("ESTOP")); break;
  }
  Serial.print(F(" armed="));  Serial.print(motorsArmed);
  Serial.print(F(" range="));  Serial.print(rangeCm, 1);
  Serial.print(F(" speed="));  Serial.print(currentSpeed);
  Serial.print(F("/"));        Serial.print(targetSpeed);
  Serial.print(F(" detect=")); Serial.print(detectLatched);
  Serial.print(F(" edges/100ms=")); Serial.print(lastEdgeRate);
  Serial.print(F(" toneHeld=")); Serial.println(toneHeldMs);
}

/** Commands set *intent* only. The state machine is derived from sensors on
 *  every control tick by updateState().
 *
 *  Keeping those two things separate is what fixes a bug the host test suite
 *  caught before this ever reached hardware: when setMotion() assigned state
 *  directly, reversing away from an obstacle overwrote OBSTACLE_HOLD with
 *  DRIVING, and forward immediately became legal again while the obstacle was
 *  still 10 cm ahead. State must be a function of the world, not of the last
 *  thing the operator typed. */
static void setMotion(Motion m) {
  if (state == State::ESTOP) { Serial.println(F("! estop engaged")); return; }
  if (!motorsArmed)          { Serial.println(F("! motors disarmed - send ARM")); return; }
  // Gate forward on the live range reading, not on a latched state flag.
  if (m == Motion::FWD && rangeCm <= CLEAR_CM) {
    Serial.println(F("! obstacle ahead - reverse or turn first"));
    return;                   // reverse and turns stay available, unlike v2
  }
  motion = m;
}

/** State is a pure function of (estop, detection, range, motion).
 *  ESTOP and TARGET_FOUND are latched and need an explicit CLEAR. */
static void updateState() {
  if (state == State::ESTOP || state == State::TARGET_FOUND) return;
  if (rangeCm <= STOP_CM) {
    state = State::OBSTACLE_HOLD;
  } else if (state == State::OBSTACLE_HOLD) {
    // Inside the hysteresis band (STOP_CM..CLEAR_CM) the hold persists, so the
    // rover cannot chatter in and out of it at the threshold.
    if (rangeCm >= CLEAR_CM)
      state = (motion == Motion::STOP) ? State::IDLE : State::DRIVING;
  } else {
    state = (motion == Motion::STOP) ? State::IDLE : State::DRIVING;
  }
}

static void handleCommand(String cmd) {
  cmd.trim();
  if (!cmd.length()) return;
  cmd.toUpperCase();
  lastCommandMs = millis();

  // Split "SPD 200" into verb + argument
  int sp = cmd.indexOf(' ');
  String verb = (sp < 0) ? cmd : cmd.substring(0, sp);
  String arg  = (sp < 0) ? ""  : cmd.substring(sp + 1);

  if      (verb == "F" || verb == "FWD"   || verb == "FORWARD") setMotion(Motion::FWD);
  else if (verb == "B" || verb == "REV"   || verb == "BACK")    setMotion(Motion::REV);
  else if (verb == "L" || verb == "LEFT")                       setMotion(Motion::LEFT);
  else if (verb == "R" || verb == "RIGHT")                      setMotion(Motion::RIGHT);
  else if (verb == "S" || verb == "STOP")                       { setMotion(Motion::STOP); halt(nullptr); }
  else if (verb == "ARM"    || verb == "ENABLE")  { motorsArmed = true;  Serial.println(F("# armed")); }
  else if (verb == "DISARM" || verb == "DISABLE") { motorsArmed = false; halt("disarmed"); }
  else if (verb == "ESTOP") { state = State::ESTOP; motorsArmed = false; halt("ESTOP"); }
  else if (verb == "CLEAR") {
    if (state == State::ESTOP)        { state = State::IDLE; Serial.println(F("# estop cleared - still disarmed")); }
    if (state == State::TARGET_FOUND) { state = State::IDLE; }
    detectLatched = false;
  }
  else if (verb == "SPD" || verb == "SPEED") {
    int v = arg.toInt();
    if (v < 0) v = 0; if (v > 255) v = 255;
    targetSpeed = (uint8_t)v;
    Serial.print(F("# speed → ")); Serial.println(targetSpeed);
  }
  else if (verb == "MARK") beginMarkerDrop();
  else if (verb == "CAL") {   // field calibration: watch the raw envelope
    Serial.print(F("# edges/100ms=")); Serial.print(lastEdgeRate);
    Serial.print(F(" threshold="));    Serial.print(DETECT_MIN_EDGES);
    Serial.print(F(" toneHeld="));     Serial.print(toneHeldMs);
    Serial.print(F("/"));              Serial.println(DETECT_CONFIRM_MS);
  }
  else if (verb == "?" || verb == "STATUS") printStatus();
  else if (verb == "HELP") {
    Serial.println(F("# F B L R S | ARM DISARM | SPD <0-255> | MARK | CAL | ESTOP CLEAR | ? HELP"));
  }
  else { Serial.print(F("! unknown: ")); Serial.println(verb); }
}

/** Drain the serial buffer without blocking. readStringUntil() in v2 blocked
 *  for up to the stream timeout on a partial line. */
static void serviceSerial() {
  while (Serial.available() > 0) {
    char ch = (char)Serial.read();
    if (ch == '\n' || ch == '\r') {
      if (rxBuffer.length()) { handleCommand(rxBuffer); rxBuffer = ""; }
    } else if (rxBuffer.length() < 64) {
      rxBuffer += ch;
    }
  }
}

// ─────────────────────────────────────────────────────────────────────────────
// Control tick
// ─────────────────────────────────────────────────────────────────────────────
static void serviceControl(uint32_t now) {
  if (toneConfirmed && !detectLatched) {
    detectLatched = true;
    state = State::TARGET_FOUND;
    halt("metal detected");
    beginMarkerDrop();
    Serial.println(F("# TARGET — send CLEAR to acknowledge"));
  }

  State before = state;
  updateState();
  if (state == State::OBSTACLE_HOLD && motion == Motion::FWD)
    halt("obstacle within threshold");
  if (before == State::OBSTACLE_HOLD && state != State::OBSTACLE_HOLD)
    Serial.println(F("# path clear"));

  // Deadman. Defect 3: v2 latched motors on forever.
  if (motion != Motion::STOP && (now - lastCommandMs) > CMD_TIMEOUT_MS) {
    setMotion(Motion::STOP);
    halt("command timeout");
  }

  // Speed ramp toward target
  uint8_t want = (motion == Motion::STOP || !motorsArmed) ? 0 : targetSpeed;
  if (currentSpeed < want)      currentSpeed = min<int>(want, currentSpeed + RAMP_STEP);
  else if (currentSpeed > want) currentSpeed = max<int>(want, currentSpeed - RAMP_STEP);

  applyMotion(motion, currentSpeed);
}

/** Fixed-rate CSV telemetry so a host can log and plot a sweep.
 *  v2 printed on every loop iteration, flooding the link at several kHz. */
static void serviceTelemetry(uint32_t now) {
  Serial.print(F("T,")); Serial.print(now);
  Serial.print(',');     Serial.print((int)state);
  Serial.print(',');     Serial.print(rangeCm, 1);
  Serial.print(',');     Serial.print(currentSpeed);
  Serial.print(',');     Serial.print(detectLatched ? 1 : 0);
  Serial.print(',');     Serial.print(lastEdgeRate);
  Serial.print(',');     Serial.println(digitalRead(PIN_IR) == LOW ? 1 : 0);
}

// ─────────────────────────────────────────────────────────────────────────────
void setup() {
  Serial.begin(115200);

  pinMode(PIN_IN1, OUTPUT); pinMode(PIN_IN2, OUTPUT);
  pinMode(PIN_IN3, OUTPUT); pinMode(PIN_IN4, OUTPUT);
  pwmInit(PIN_ENA, CH_A);
  pwmInit(PIN_ENB, CH_B);

  pinMode(PIN_TRIG, OUTPUT);
  pinMode(PIN_ECHO, INPUT);
  pinMode(PIN_IR, INPUT);
  pinMode(PIN_DETECT, INPUT);
  attachInterrupt(digitalPinToInterrupt(PIN_DETECT), onDetectorEdge, CHANGE);

  markerServo.setPeriodHertz(50);
  markerServo.attach(PIN_SERVO, 500, 2400);
  markerServo.write(SERVO_STOWED);

  halt(nullptr);
  lastCommandMs = millis();

  Serial.println(F("# MineRoverX v3 ready. Motors DISARMED."));
  Serial.println(F("# F B L R S | ARM DISARM | SPD <0-255> | MARK | CAL | ESTOP CLEAR | ? HELP"));
  Serial.println(F("# telemetry: T,ms,state,range_cm,speed,detect,edges,ir"));
}

void loop() {
  uint32_t now = millis();

  serviceSerial();                       // never gated — always runs

  if (now - lastRangeMs >= RANGE_PERIOD_MS) {
    lastRangeMs = now;
    rangeCm = pingMedian3();
  }
  serviceDetector(now);

  if (now - lastCtrlMs >= CTRL_PERIOD_MS) {
    lastCtrlMs = now;
    serviceControl(now);
    serviceMarker(now);
  }
  if (now - lastTelemMs >= TELEM_PERIOD_MS) {
    lastTelemMs = now;
    serviceTelemetry(now);
  }
}

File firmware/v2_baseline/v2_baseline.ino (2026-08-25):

// === CONFIGURATION ===

// Motor driver pins (L298N - DC Gear Motors)
const int enA = 27;    // ENA -> PWM (Motor A speed) Right side motor
const int in1 = 26;    // IN1
const int in2 = 25;    // IN2
const int enB = 5;     // ENB -> PWM (Motor B speed)  Left side motor
const int in3 = 18;    // IN3
const int in4 = 19;    // IN4

// Ultrasonic Sensor Pins
const int trigPin = 17;
const int echoPin = 16;

// Motor parameters
int motorSpeed = 180;      // PWM value (0-255)
bool motorsEnabled = true;
const int stopDistance = 15; // cm

// === SETUP ===

void setup() {
  Serial.begin(115200);

  // Setup L298N pins
  pinMode(enA, OUTPUT);
  pinMode(in1, OUTPUT);
  pinMode(in2, OUTPUT);
  pinMode(enB, OUTPUT);
  pinMode(in3, OUTPUT);
  pinMode(in4, OUTPUT);

  // Ultrasonic sensor pins
  pinMode(trigPin, OUTPUT);
  pinMode(echoPin, INPUT);

  disableMotors();

  Serial.println("ESP32 + L298N + Ultrasonic Sensor Bot Initialized.");
  Serial.println("Commands: enable, disable, forward, back, left, right, stop");
}

// === MAIN LOOP ===

void loop() {
  float distance = getDistance();

  if (distance <= stopDistance) {
    stopMotors();
    Serial.println("⚠️ Object detected within 15 cm! Stopping...");
    delay(100);
    return;
  } else {
    Serial.println("✅ Path is clear.");
    Serial.println("💬 Waiting for command...");
    // ⚠️ DO NOT return here
  }

  if (Serial.available() > 0) {
    String command = Serial.readStringUntil('\n');
    command.trim();
    command.toLowerCase();

    if (command == "enable") {
      motorsEnabled = true;
      Serial.println("Motors enabled.");
    }
    else if (command == "disable") {
      motorsEnabled = false;
      disableMotors();
      Serial.println("Motors disabled.");
    }
    else if (motorsEnabled) {
      if (command == "forward") {
        moveForward();
        Serial.println("Moving forward...");
      }
      else if (command == "back") {
        moveBackward();
        Serial.println("Moving backward...");
      }
      else if (command == "left") {
        turnLeft();
        Serial.println("Turning left...");
      }
      else if (command == "right") {
        turnRight();
        Serial.println("Turning right...");
      }
      else if (command == "stop") {
        stopMotors();
        Serial.println("Motors stopped.");
      }
      else {
        Serial.println("Unknown command.");
      }
    }
    else {
      Serial.println("Motors are disabled. Type 'enable' to activate.");
    }
  }
}


// === ULTRASONIC SENSOR FUNCTION ===

float getDistance() {
  digitalWrite(trigPin, LOW);
  delayMicroseconds(2);
  digitalWrite(trigPin, HIGH);
  delayMicroseconds(10);
  digitalWrite(trigPin, LOW);

  long duration = pulseIn(echoPin, HIGH, 20000); // 20ms timeout
  float distance = duration * 0.0343 / 2; // cm
  return distance;
}

// === MOTOR CONTROL FUNCTIONS ===

void moveForward() {
  digitalWrite(in1, HIGH); digitalWrite(in2, LOW);
  digitalWrite(in3, HIGH); digitalWrite(in4, LOW);
  analogWrite(enA, motorSpeed);
  analogWrite(enB, motorSpeed);
}

void moveBackward() {
  digitalWrite(in1, LOW); digitalWrite(in2, HIGH);
  digitalWrite(in3, LOW); digitalWrite(in4, HIGH);
  analogWrite(enA, motorSpeed);
  analogWrite(enB, motorSpeed);
}

void turnLeft() {
  digitalWrite(in1, HIGH); digitalWrite(in2, LOW);
  digitalWrite(in3, LOW); digitalWrite(in4, HIGH);
  analogWrite(enA, motorSpeed);
  analogWrite(enB, motorSpeed);
}

void turnRight() {
  digitalWrite(in1, LOW); digitalWrite(in2, HIGH);
  digitalWrite(in3, HIGH); digitalWrite(in4, LOW);
  analogWrite(enA, motorSpeed);
  analogWrite(enB, motorSpeed);
}

void stopMotors() {
  digitalWrite(in1, LOW); digitalWrite(in2, LOW);
  digitalWrite(in3, LOW); digitalWrite(in4, LOW);
  analogWrite(enA, 0);
  analogWrite(enB, 0);
}

void disableMotors() {
  stopMotors();
  digitalWrite(enA, LOW);
  digitalWrite(enB, LOW);
}

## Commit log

2026-08-25 Preserve v2 firmware as shipped, plus hardware BOM and CAD sources
    [chassis_v1.step, chassis_v2.step, dumper_v4.f3d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]
2026-08-25 Add host-side test suite with stubbed Arduino HAL (42 tests) and CI
2026-08-25 Add wiring and state-machine diagrams
2026-08-25 Add photographs of the assembled rover

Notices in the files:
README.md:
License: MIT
